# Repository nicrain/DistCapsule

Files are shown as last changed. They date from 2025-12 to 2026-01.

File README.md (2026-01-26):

# Distributeur de Capsules Intelligent (Smart Capsule Dispenser)



**Plateforme:** Raspberry Pi 5 (Bookworm OS) | **État:** Stable (V1.1) | **Dernière mise à jour:** 2026-01-26

Un système de distribution de capsules sécurisé et activé par biométrie. Il transforme un présentoir à capsules standard en un système de "boîte aux lettres" personnalisé où chaque utilisateur a un accès exclusif à un canal de stockage spécifique via une authentification par empreinte digitale. Le système prend en charge l'enregistrement multi-utilisateurs, la hiérarchie des permissions (Admin/Utilisateur) et l'allocation dynamique des canaux physiques.

---

## ✨ Fonctionnalités Clés

*   **Gestion des Rôles Multi-utilisateurs**: Authentification par Token persistante avec connexion automatique (Auto-Login).
*   **Architecture IoT Moderne**: Écosystème complet intégrant l'App Android, le serveur FastAPI et le contrôle matériel en temps réel.
*   **Architecture Multi-threadée**: Threads séparés pour l'IA (visage), l'UI et la gestion des commandes réseau.
*   **UX Mobile Avancée (V1.1)**: Interface visuelle et colorée (Vivid Palette), icône d'application personnalisée, animations de sélection et retour haptique visuel.

---

## 🛠 Architecture Matérielle

*   **Contrôleur**: Raspberry Pi 5 (Recommandé 8Go).
*   **Actionneurs**: 5x Micro servomoteurs SG90 (9g).
*   **Capteur**: Module capteur d'empreintes optique DY-50 / R307 (UART).
*   **Interface**: Écran LCD IPS 1.3" (ST7789) + **Bouton Poussoir (Wake-Up)** pour le réveil du système.
*   **Base**: Composants imprimés en 3D sur mesure. Les premières ébauches sont disponibles dans le répertoire `3D/`.
*   **Alimentation**:
    *   Pi 5: Alimentation officielle USB-C 27W.
    *   Servos: **Alimentation externe 5V** (Masse commune avec le Pi obligatoire).

> **⚠️ Avertissement de Câblage**: Ne pas alimenter 5 servomoteurs directement depuis la broche 5V du GPIO du Pi. Utilisez une source d'alimentation externe. Voir [WIRING_GUIDE.md](docs/WIRING_GUIDE.md) pour les détails de câblage.

---

## 🚀 Installation et Configuration

### 1. Dépendances Système
Le projet dépend de `lgpio` pour le contrôle GPIO sur le Pi 5 et de `pyserial` pour le capteur.

```bash
sudo apt-get update
sudo apt-get install python3-serial python3-pip python3-lgpio python3-pil python3-rpi.gpio
```

### 2. Bibliothèques Python
```bash
sudo pip3 install adafruit-circuitpython-fingerprint st7789
```

### 3. Environnement de Reconnaissance Faciale (Pi 5 Bookworm)
Le système d'exploitation Raspberry Pi OS Bookworm empêche l'installation directe via `pip`. Utilisez l'une des méthodes suivantes :

**Pré-requis (Pi 5) : Pilotes GStreamer**
Pour que la caméra fonctionne avec OpenCV sur le Pi 5, vous devez installer les plugins GStreamer :
```bash
sudo apt install libgstreamer1.0-dev libgstreamer-plugins-base1.0-dev \
gstreamer1.0-plugins-base gstreamer1.0-plugins-good gstreamer1.0-plugins-bad \
gstreamer1.0-libcamera gstreamer1.0-tools
```

**Méthode A : APT (Recommandé)**
```bash
sudo apt update
sudo apt install python3-opencv python3-face-recognition
```

**Méthode B : PIP (Si APT échoue)**
```bash
# L'option --break-system-packages est requise hors d'un environnement virtuel
pip3 install opencv-python face_recognition setuptools --break-system-packages

# ⚠️ Si vous rencontrez l'erreur "Please install `face_recognition_models`" :
pip install git+https://github.com/ageitgey/face_recognition_models --break-system-packages
```

### 4. Configuration Matérielle
*   **UART**: Activez le matériel du port série via `sudo raspi-config`, mais désactivez le shell de connexion. Le module d'empreintes digitales utilise `/dev/ttyAMA0` (GPIO 14/15) sur le Pi 5.
*   **SPI**: Activez l'interface SPI via `sudo raspi-config` pour l'écran.

### 5. Configuration Réseau (Zéro-Config)
Utilisez le script d'installation automatisé pour configurer le Hotspot, l'API et le contrôleur matériel comme services système :

```bash
cd tools
sudo ./install_service.sh
```
*   **SSID** : `DistCapsule_Box` (IP: 192.168.4.1)
*   **Mot de passe** : `capsule_admin`
*   **Port API** : 8000
*   **Démarrage** : Automatique au boot du Pi.

> 🔧 **Administration** : Pour les détails sur l'accès SSH, les logs système et la maintenance SQL, consultez le [**Guide d'Administration (SYSADMIN_GUIDE)**](docs/SYSADMIN_GUIDE.md).

---

## 📱 Application Android (V1.1)

L'application (dossier `android/`) a été optimisée pour une fluidité maximale :

*   **Vivid UI** : Palette de couleurs moderne (Émeraude, Tournesol, Corail) avec texte contrasté pour une lisibilité parfaite.
*   **Auto-Login** : Une fois enregistré, l'accès au Dashboard est instantané.
*   **Connexion Wi-Fi Simplifiée** : Un bouton dédié permet de se connecter automatiquement au hotspot `DistCapsule_Box` sans saisir de mot de passe (Android 10+) ou en ouvrant directement les paramètres (Android 9).
*   **Saisie d'IP Simplifiée** : Entrez simplement l'IP, le protocole et le port sont gérés automatiquement.
*   **Gestion de Compte Sécurisée** : Bouton "Supprimer mon compte" avec nettoyage automatique du token local et des données biométriques sur le matériel.
*   **Feedback Visuel Avancé** : Animation "Pop-up" lors de la sélection des canaux (style réservation de place) et transitions fluides entre les menus.
*   **Navigation Fluide** : Ajout de boutons de retour et gestion intelligente du clavier virtuel pour une expérience sans friction.
*   **Sécurité Administrateur** : Protection contre la suppression accidentelle du compte admin et verrouillage des modifications pour le profil administrateur dans la console de gestion.
*   **Version Production V1.1** : Écosystème IoT complet avec application Android native (Java), serveur FastAPI et agent Python sur Pi 5.
*   **Auto-Guérison (Watchdog)** : Surveillance active du capteur d'empreintes avec réinitialisation automatique en cas de défaillance.
*   **Soutenance & Documentation** : Support de présentation LaTeX complet (21 slides) détaillant l'architecture AAA, les défis techniques et les choix d'ingénierie.
*   **Sécurité \& RGPD** : Authentification par token, protection des comptes administrateurs et fonction "Droit à l'oubli" (nettoyage complet des données biométriques).

---

## 📖 Guide d'Utilisation

### 1. Inscription
Ouvrez l'application, entrez votre nom et cliquez sur "Créer et se connecter". Un canal libre vous sera automatiquement attribué si disponible.

### 2. Administration
Pour activer les privilèges Admin sur un compte :
```bash
sqlite3 capsule_dispenser.db "UPDATE Users SET auth_level=1 WHERE user_id=1;"
```

### 3. Enrôlement Biométrique
Les utilisateurs peuvent lancer l'enrôlement de leur visage ou empreinte directement depuis leur Dashboard. L'écran du Pi s'allume alors automatiquement pour guider l'utilisateur.

---

## 📂 Structure du Projet

| Fichier/Dossier | Description |
| :--- | :--- |
| `main.py` | Cœur du système (Hardware Loop). |
| `api/server.py` | API REST FastAPI. |
| `android/` | Projet Android Studio (Java). |
| `hardware/` | Drivers et logique d'enrôlement. |
| `tools/` | Scripts d'installation et maintenance. |

---

## 🔮 Feuille de Route Future

*   **Notifications Push** : Alertes mobiles en cas d'accès non autorisé.
*   **Logs Avancés** : Historique détaillé des accès avec photos des visages.
*   **Design 3D** : Finalisation de la coque de protection.

---

## 📜 Histoire & Décisions

*   **2026-01-18 (V1.1)** : Refonte de l'UX Android, ajout de l'auto-login et sécurisation des timeouts matériels.
*   **2026-01-14 (V1.0)** : Première release stable IoT (App + API + Pi).
*   **2025-12 (S5)** : Migration vers `lgpio` et architecture asynchrone.

---

*   **Note** : Le projet a abandonné le support MQTT et le suivi des stocks physiques pour se concentrer sur la fiabilité de l'accès biométrique.

## License
MIT License

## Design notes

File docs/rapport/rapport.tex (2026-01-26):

% !TEX program = pdflatex
\documentclass[a4paper,12pt]{report}

\usepackage[T1]{fontenc}
\usepackage[utf8]{inputenc}
\usepackage[french]{babel}
\usepackage{lmodern}
\usepackage{helvet}
\renewcommand{\familydefault}{\sfdefault}

\usepackage{geometry}
\geometry{margin=2.5cm}

\usepackage{graphicx}
\graphicspath{{../slides/pic/}}
\usepackage{float}
\usepackage{booktabs}
\usepackage{longtable}
\usepackage{array}
\usepackage{multirow}
\usepackage{hyperref}
\hypersetup{colorlinks=true, linkcolor=blue, urlcolor=blue, citecolor=blue}

\usepackage{listings}
\usepackage{xcolor}
\lstset{
  basicstyle=\ttfamily\small,
  keywordstyle=\color{blue!70!black}\bfseries,
  commentstyle=\color{gray!70},
  stringstyle=\color{green!40!black},
  breaklines=true,
  frame=single,
  numbers=left,
  numberstyle=\tiny\color{gray},
  showstringspaces=false
}

\usepackage{tikz}
\usetikzlibrary{shapes,arrows,positioning}

\title{DistCapsule : Distributeur connecté biométrique de capsules\\Projet AAA }
\author{Zhaoyu WANG \and Xinqi TANG}
\date{\today}

\begin{document}

% Page de titre sans numéro
\pagenumbering{gobble}
\begin{titlepage}
\centering
\noindent
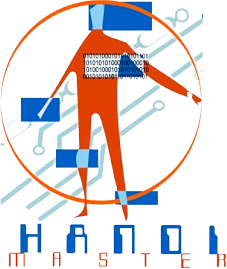
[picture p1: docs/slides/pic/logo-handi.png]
\hfill
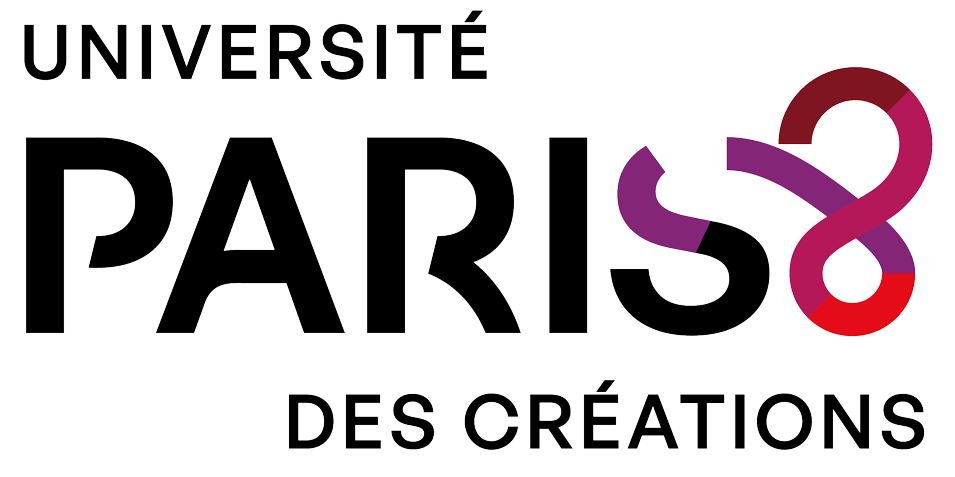
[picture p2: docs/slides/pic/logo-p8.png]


\vspace{0.6cm}

{\large Rapport du Projet AAA\par}

\vspace*{1.6cm}

{\LARGE\bfseries DistCapsule \par}
\vspace{0.4cm}

\vspace{1.4cm}

{\large Zhaoyu WANG \; et \; Xinqi TANG\par}

\vspace{0.8cm}

{\large Professeurs encadrants :\\
Salvatore Anzalone et Dominique Archambault\par}

\vfill

{\large Université Paris 8\\Master Technologies et Handicaps\par}
\vspace{0.4cm}
%{\large \today\par}
\end{titlepage}

% Préliminaires (numérotation romaine)
\cleardoublepage
\pagenumbering{roman}
\pagestyle{plain}

\begin{abstract}
DistCapsule a pour objectif de transformer un présentoir à capsules (5 canaux) en un système embarqué \textbf{sécurisé et personnalisé}.
L’accès aux canaux est contrôlé par biométrie (empreinte et/ou visage) avec gestion multi-utilisateurs et hiérarchie des droits (admin / utilisateur).

L’architecture suit un modèle AAA (3-tiers) : \textbf{Android} pour l’IHM, \textbf{FastAPI} comme passerelle (authentification, orchestration et insertion en base), et \textbf{Raspberry Pi 5} comme exécutant (polling des commandes, contrôle des servos, affichage, biométrie locale).
Ce rapport synthétise les choix techniques, l’implémentation (code), la partie mécanique (fabrication 3D) et les résultats obtenus.
\end{abstract}

\cleardoublepage
\tableofcontents

% Corps du rapport (numérotation arabe)
\cleardoublepage
\pagenumbering{arabic}

\chapter{Contexte et objectifs}
\section{Constat}
Dans un espace café partagé, les capsules sont souvent mélangées ou stockées de manière dispersée, ce qui entraîne :
\begin{itemize}
  \item une occupation inutile de l'espace ;
  \item une organisation difficile (capsules mélangées, accès non contrôlé) ;
  \item une difficulté pour les utilisateurs à identifier leurs propres stocks.
\end{itemize}

\section{Objectifs et contraintes}
En s’appuyant sur le cahier des charges et sur l’implémentation finale, les objectifs sont :
\begin{itemize}
  \item transformer le présentoir en un système à \textbf{5 canaux indépendants} (logique de « boîte aux lettres ») ;
  \item supporter au moins 5 utilisateurs, avec deux rôles : \textbf{administrateur / utilisateur} ;
  \item réaliser la biométrie et le stockage \textbf{en local} (pas de cloud) pour la confidentialité ;
  \item fournir une application Android pour l’inscription, l’affectation des canaux, l’enrôlement et l’ouverture ;
  \item s’adapter aux spécificités du Raspberry Pi 5, notamment la compatibilité GPIO (puce RP1).
\end{itemize}

\chapter{Architecture globale (AAA / 3-tiers)}
\section{Rôles des composants}
Le système est structuré en trois couches :
\begin{itemize}
  \item \textbf{Android (Client)} : interface utilisateur, persistance du token, gestion des comptes et affectation visuelle des canaux.
  \item \textbf{FastAPI (Gateway)} : API REST, authentification via token, accès SQLite, mise en file des commandes (table \texttt{Pending\_Commands}).
  \item \textbf{Core Agent (Executor, Pi 5)} : polling des commandes, action matérielle (servos/écran), biométrie locale, journalisation.
\end{itemize}

\section{Schéma d'architecture}
\begin{figure}[H]
  \centering
  \begin{tikzpicture}[node distance=2.6cm, auto, thick]
    \node[draw, fill=green!20, minimum height=1.2cm, minimum width=3.2cm, align=center] (Android) {\textbf{Android}\\Client};
    \node[draw, fill=blue!20, minimum height=1.2cm, minimum width=3.4cm, align=center, right=3.5cm of Android] (API) {\textbf{FastAPI}\\Gateway};
    \node[draw, fill=red!20, minimum height=1.2cm, minimum width=3.6cm, align=center, right=3.5cm of API] (Pi) {\textbf{Raspberry Pi 5}\\Core Agent};

    \draw[<->] (Android) -- node[above] {REST / JSON} (API);
    \draw[<->] (API) -- node[above] {SQLite\,+ Polling} (Pi);
  \end{tikzpicture}
  \caption{Architecture AAA (3-tiers) de DistCapsule}
\end{figure}

\section{Flux de données (chaîne de traitement)}
Exemple de scénario : l'utilisateur demande l'ouverture d'un canal depuis l'application.
\begin{enumerate}
  \item l'application envoie \texttt{POST /command/unlock?channel=\{1..5\}} ;
  \item FastAPI insère une entrée dans \texttt{Pending\_Commands} (statut \texttt{pending}) ;
  \item le Core Agent récupère la commande la plus ancienne, passe en \texttt{processing} ;
  \item le Core Agent actionne le servo, met à jour l'écran, et journalise dans \texttt{Access\_Logs} ;
  \item la commande est marquée \texttt{completed} ; l'application peut consulter l'état des commandes d'enrôlement via \texttt{/command/poll/\{user\_id\}}.
\end{enumerate}

\begin{figure}[H]
  \centering
  
  \caption{Schéma de flux de données}
\end{figure}

\section{Réseau : topologie et mode de déploiement}
Pour fonctionner sans Internet, le Raspberry Pi 5 opère en mode point d'accès Wi-Fi :
\begin{itemize}
  \item SSID : \texttt{DistCapsule\_Box} (réseau typique \texttt{192.168.4.x}, Pi souvent \texttt{192.168.4.1}) ;
  \item API : port \texttt{8000} ;
  \item administration : liaison Ethernet \texttt{eth0} vers un PC (réseau typique \texttt{192.168.3.x}, Pi souvent \texttt{192.168.3.14}) pour SSH et diagnostic.
\end{itemize}

\begin{figure}[H]
  \centering
  \begin{tikzpicture}[node distance=2.5cm, auto, thick]
    \node[draw, fill=green!20, minimum size=0.9cm, align=center] (Phone) {\textbf{Application}\\Android};
    \node[draw, fill=red!20, minimum width=3.2cm, minimum height=1.2cm, align=center, right=3.0cm of Phone] (Pi) {\textbf{Raspberry Pi 5}\\wlan0 (Point d'accès) + eth0};
    \node[draw, fill=blue!20, minimum size=0.9cm, align=center, right=3.0cm of Pi] (PC) {\textbf{Poste admin}\\SSH/Logs};
    \draw[<->] (Phone) -- node[above] {Wi-Fi} node[below] {192.168.4.x} (Pi);
    \draw[<->] (Pi) -- node[above] {RJ45} node[below] {192.168.3.x} (PC);
  \end{tikzpicture}
  \caption{Topologie réseau (point d'accès Wi-Fi + Ethernet)}
\end{figure}

\chapter{Matériel et câblage}
\section{Périphériques intégrés}
\begin{itemize}
  \item Contrôleur : Raspberry Pi 5 ;
  \item Actionneurs : 5 servomoteurs SG90 ;
  \item Capteurs : empreinte DY-50 (UART), Camera Module 3 (CSI) ;
  \item IHM locale : écran IPS 1.3\," ST7789 (SPI) + bouton de réveil (GPIO 26).
\end{itemize}

\section{Câblage et alimentation}
\subsection{Servos : mapping GPIO (Soft-PWM)}
L'implémentation utilise \texttt{lgpio} en PWM logiciel pour piloter 5 servos (contournement des canaux PWM matériels limités sur Pi 5 et incompatibilité RPi.GPIO) :

\begin{table}[H]
\centering
\begin{tabular}{llll}
\toprule
Canal (servo) & BCM GPIO & Broche (Pin) & Remarque \\
\midrule
1 & 18 & Pin 12 & Compatible Hard PWM , utilisé en Soft PWM \\
2 & 6  & Pin 31 & Soft PWM \\
3 & 12 & Pin 32 & Soft PWM \\
4 & 13 & Pin 33 & Soft PWM \\
5 & 19 & Pin 35 & Soft PWM \\
\bottomrule
\end{tabular}
\caption{Mapping des canaux vers GPIO (implémentation)}
\end{table}

\subsection{Écran (SPI) et empreinte (UART)}
\begin{itemize}
  \item ST7789 : SPI0 (SCLK/MOSI) + DC/RESET/BLK via GPIO ;
  \item Empreinte : \texttt{/dev/ttyAMA0} (GPIO 14/15), TX/RX croisés.
\end{itemize}

\subsection{Alimentation et stabilité}
\begin{itemize}
  \item Les servos sont alimentés par une source 5V externe, avec masse commune avec le Pi ;
  \item Un condensateur (ex. 500\,$\mu$F) est intégré pour amortir les pics de courant.
\end{itemize}

\begin{figure}[H]
  \centering
  
  \caption{Schéma de câblage}
\end{figure}

\chapter{Conception et fabrication 3D}
\section{Fabrication additive}
La modélisation a été réalisée de manière paramétrique avec \textbf{SolidPython2} (interface Python pour OpenSCAD), ce qui a facilité l'ajustement des tolérances et la génération des fichiers STL.

Les pièces ont été imprimées en PLA sur une durée cumulée d'environ 4 jours.
\subsection{Stratégie d'itération}
Pour limiter les itérations longues, l'ajustement dimensionnel a été validé par \textit{prototypage partiel} : au lieu d'imprimer directement les grandes pièces (base, tour), des « échantillons » (ex. encoche du servo, section de rail) ont été imprimés afin de vérifier les contraintes physiques et les tolérances. Cette méthode réduit le coût matière/temps et fiabilise les dimensions avant impression finale.

\begin{figure}[H]
  \centering
  
  \caption{Rendu 3D OpenSCAD du corps principal (structure porteuse)}
\end{figure}

\chapter{Implémentation logicielle}
\section{Core Agent (Pi 5) : boucle principale}
Le cœur du système s'exécute dans \texttt{main.py}. Principes de fonctionnement :
\begin{itemize}
  \item \textbf{SLEEP/ACTIVE} : veille par défaut (rétro-éclairage éteint), réveil par bouton ou commande applicative ;
  \item \textbf{Interrogation périodique (polling)} : lecture des commandes en base (ouverture / enrôlement / suppression) ;
  \item \textbf{Biométrie} : empreinte au premier plan, visage via un fil d'exécution en arrière-plan (file) ;
  \item \textbf{Temporisations} : mise en veille sur inactivité (\texttt{SCREEN\_TIMEOUT}) et durée maximale de session (\texttt{MAX\_SESSION\_TIME}).
\end{itemize}

\section{Passerelle FastAPI (api/server.py)}
FastAPI gère les utilisateurs, l'authentification par token et la mise en file des commandes.
\begin{itemize}
  \item \texttt{POST /users} : création (avec auto-affectation du premier canal libre) ;
  \item \texttt{POST /auth} : auto-login via token lié à l'appareil ;
  \item \texttt{POST /command/unlock}, \texttt{/command/enroll\_...} : insertion dans \texttt{Pending\_Commands}.
\end{itemize}

\section{Application Android : fonctionnalités et intégration}
L'application Android (Java) fournit l'interface utilisateur et s'intègre à l'API via des appels REST/JSON.
Fonctions principales :
\begin{itemize}
  \item \textbf{Authentification} : auto-login par token UUID persisté localement ;
  \item \textbf{Gestion des utilisateurs} : inscription, suppression (selon droits), affectation de canal ;
  \item \textbf{Opérations} : déclenchement d'ouverture de canal et d'enrôlement biométrique via commandes côté API ;
  \item \textbf{Retour d'état} : affichage des canaux et des statuts (disponible/occupé) à partir des données serveur.
\end{itemize}

\begin{figure}[H]
  \centering
  
  \caption{Tableau de bord Android}
\end{figure}

\section{Base de données (SQLite)}
La base est initialisée via \texttt{tools/setup\_database.py}. Tables principales :
\begin{itemize}
  \item \texttt{Users} : identité, droits, canal, token, encodage visage (JSON), statut empreinte ;
  \item \texttt{Access\_Logs} : journal d'événements ;
  \item \texttt{Pending\_Commands} : file de commandes (pending/processing/completed).
\end{itemize}

\section{Biométrie (Visage et Empreinte)}
\begin{itemize}
  \item \textbf{Visage} : \texttt{face\_recognition} (dlib) sur flux vidéo GStreamer/libcamera.
  \item \textbf{Empreinte} : Module DY-50, stockage du modèle dans la mémoire interne du capteur (slot = ID utilisateur).
\end{itemize}

\chapter{Sécurité, confidentialité et approche RGPD}
\section{Confidentialité by design}
\begin{itemize}
  \item Les données biométriques restent \textbf{locales} (pas d'envoi vers un cloud) ;
  \item L'application et l'API n'échangent que le token et les paramètres de commande ;
  \item La suppression d'un compte entraîne la suppression des données associées (base + nettoyage côté capteur).
\end{itemize}

\section{Droits et protection}
\begin{itemize}
  \item L'API interdit la suppression du compte administrateur ;
  \item L'application isole les fonctions d'administration (affectation des canaux) des fonctions utilisateurs.
\end{itemize}

\chapter{Tests et résultats}
\section{Validation bout-en-bout}
Chaînes fonctionnelles validées :
\begin{itemize}
  \item Inscription via l'application $\rightarrow$ token $\rightarrow$ auto-login ;
  \item Enrôlement $\rightarrow$ guidage à l'écran $\rightarrow$ stockage DB/capteur ;
  \item Commande d'ouverture $\rightarrow$ insertion DB $\rightarrow$ exécution mécanique.
\end{itemize}

\section{Limites connues}
\begin{itemize}
  \item Le capteur d'empreintes peut se bloquer (UART) ; une réinitialisation (capteur et/ou service) est parfois nécessaire.
  \item En mode point d'accès, certains téléphones peuvent basculer sur les données mobiles (4G/5G) ; le réglage "Rester connecté" peut être nécessaire.
\end{itemize}

\chapter{Conclusion et perspectives}
DistCapsule est un \textbf{prototype fonctionnel} intégrant application Android, API FastAPI et exécution matérielle sur Raspberry Pi 5.
Il démontre la faisabilité d'un système embarqué connecté sécurisé, respectueux de la vie privée (approche locale) et multi-utilisateurs.

Perspectives :
\begin{itemize}
  \item Améliorer la robustesse du module d'empreintes (gestion d'erreurs UART, stratégie de réinitialisation, éventuellement changement de capteur) ;
  \item Finaliser l'assemblage 3D complet et documenter les tolérances d'impression (PLA) ;
  \item Remplacer le polling par un mécanisme push (ex. WebSockets) pour réduire la latence et la charge ;
  \item Finaliser la logique d'affectation automatique (notamment le canal 1) pour garantir la cohérence UI/API/SQLite lors d'ajouts/suppressions.
\end{itemize}

\appendix
\chapter{Références}
\begin{thebibliography}{9}
  \bibitem{fastapi} FastAPI Documentation. \url{https://fastapi.tiangolo.com/}
  \bibitem{rpi5} Raspberry Pi Documentation. \url{https://www.raspberrypi.com/documentation/}
  \bibitem{android} Android Developers. \url{https://developer.android.com/}
\end{thebibliography}

\end{document}

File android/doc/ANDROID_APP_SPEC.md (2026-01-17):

# 📱 DistCapsule Android App Specification (V2.0)

**Project Name**: DistCapsule (Smart Coffee Capsule Dispenser)
**Target Platform**: Android (Min SDK 24+)
**Backend**: Raspberry Pi 5 (FastAPI REST)
**Version**: 2.0 (Updated 2026-01-16)

---

## 1. Project Overview

The Android application serves as the primary **Control & Management Interface** for the DistCapsule system. It connects to the Raspberry Pi via local Wi-Fi (Hotspot `DistCapsule_Box`) and provides two distinct views based on user roles:
1.  **Administrator**: Full system management (Users, Channels, Hardware).
2.  **Standard User**: Personal coffee retrieval and profile management.

---

## 2. User Roles & Features

### 2.1 Administrator (Admin)
*   **User Management**:
    *   Create new users (Name, Permission).
    *   Assign/Reassign coffee channels (Rails 1-5).
    *   Trigger remote biometric enrollment (Face/Fingerprint).
    *   Delete users (including hardware data cleanup).
    *   *Note*: The App must handle **HTTP 400 errors** if assigning a channel that is already occupied by another user.
*   **Hardware Control**:
    *   Manually open any channel (Maintenance).
    *   View real-time channel occupancy map.

### 2.2 Standard User
*   **One-Tap Dispense**:
    *   Large button "Get My Coffee" (Ouvrir mon canal).
    *   Only works if the user has an assigned channel.
*   **Self-Management**:
    *   Delete own account (GDPR compliance / Unregister).
*   **Visualization**:
    *   View the "Coffee Map" (Which channel is occupied by whom).

---

## 3. App Workflow & UX

### 3.1 Onboarding & Login (Token Based)
*   **No Password**: The app uses a device-bound **Token** for authentication.
*   **First Run (New User)**:
    1.  App scans for the API (`GET /`).
    2.  User clicks "Register".
    3.  App generates a UUID Token.
    4.  **Registration**: App sends Name + Token to server (`POST /users`).
    5.  Server creates user and binds the token immediately.
*   **First Run (Existing User - Lost Phone)**:
    *   *Note*: To prevent identity theft, users cannot self-bind to an existing account.
    *   **Process**: Ask Admin to reset the old binding, or register as a new user.
*   **Subsequent Runs**:
    1.  App sends Token (`POST /auth`).
    2.  Server returns user profile.
    3.  App jumps directly to the Dashboard.

### 3.2 Dashboard (Main Screen)
*   **Header**: "Bonjour, [Name]".
*   **Status Card**: Display icons indicating biometric status (e.g., "Face: ✅ | Finger: ❌") so users know if they are fully enrolled.
*   **Center**:
    *   If **User** + **Assigned Channel**: Big Green Button `[ DISPENSE ]`.
    *   If **Admin**: Grid view of 5 Channels with control buttons.
    *   If **No Channel**: "Waiting for assignment / En attente".
*   **Footer**: "Channel Map" (List of who owns which channel).

### 3.3 Enrollment (Admin Only)
*   Inside User Details:
    *   Button `[ Enroll Face ]` -> Triggers Pi camera mode.
    *   Button `[ Enroll Finger ]` -> Triggers Pi fingerprint sensor mode.
*   **Feedback**: App should show a toast "Enrollment Started, please follow instructions on the machine screen".
*   **Best Practice**: The App should automatically **refresh the user list (`GET /users`)** after a few seconds to update the `has_face` / `has_fingerprint` status icons.

---

## 4. Technical Architecture

### 4.1 Network
*   **Protocol**: HTTP REST (JSON).
*   **Address**: `http://192.168.4.1:8000` (Default Hotspot Gateway).
*   **Constraint**: The phone must stay connected to the Pi's Wi-Fi.

### 4.2 Data Models
*   **User**: `id`, `name`, `auth_level` (1=Admin, 2=User), `assigned_channel` (1-5 or null), `has_face` (bool), `has_fingerprint` (bool).
*   **Command**: The App does not control servos directly. It sends **Commands** (`UNLOCK`, `ENROLL`) to the API, which queues them for the Hardware Agent (`main.py`).

---

## 5. Developer Guide (Next Steps)
For detailed API endpoints, parameters, and JSON examples, please refer to the **[API Reference Documentation](API_REFERENCE.md)**.

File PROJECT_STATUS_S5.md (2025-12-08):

# 智能胶囊分配器 - 项目状态文档 (S5.1)
**日期:** 2025-12-08
**平台:** Raspberry Pi 5 (Bookworm OS)

## 1. 项目概况
本项目旨在构建一个基于 Raspberry Pi 5 的离线智能胶囊分配器。系统通过生物识别（指纹/人脸）验证用户身份，并控制高扭矩舵机分配胶囊。

## 2. 核心架构决策

| 模块 | 决策/规格 | 状态 | 备注 |
| :--- | :--- | :--- | :--- |
| **主控** | Raspberry Pi 5 | ✅ 就绪 | 运行 Raspberry Pi OS (Bookworm) |
| **舵机控制** | **SG90 (9g)** / 软件 PWM | ✅ 更新 | **关键变更**: 从硬件 PWM 迁移到软件 PWM (`lgpio`) 以解决与系统风扇的冲突 |
| **显示屏** | **1.3" IPS (ST7789)** | ✅ 完成 | 240x240, SPI 接口, 自定义驱动 `st7789_driver.py` |
| **数据库** | SQLite (`capsule_dispenser.db`) | ✅ 完成 | 已集成到主程序，支持用户查询和日志记录 |
| **指纹模块** | DY-50 (类 R307) | ✅ 完成 | 解决了 Pi 5 特有的串口映射问题 (`ttyAMA0`) |
| **散热** | 系统风扇 (Active Cooler) | ✅ 恢复 | 由系统内核自动控制，不再占用 GPIO 19 |

---

## 3. 详细技术实现

### 3.1 舵机控制系统 (Servo System)
**重大架构变更 (2025-12-08)**:
由于 Raspberry Pi 5 的硬件 PWM 模块与系统风扇驱动 (`pwm-fan`) 共享时钟源，当风扇启动时，PWM 频率会被强制锁定在 ~25kHz，导致舵机 (需要 50Hz) 失效。
因此，我们将舵机控制迁移到了 **软件 PWM (Software PWM)**，使用 `lgpio` 库直接控制 GPIO 电平。

*   **硬件型号**: SG90 (Micro Servo 9g) x 4
*   **接口分配**:
    *   **Servo 1**: GPIO 18
    *   **Servo 2**: GPIO 12
    *   **Servo 3**: GPIO 13
    *   **Servo 4**: GPIO 19 (已恢复)
*   **系统配置**:
    不再需要复杂的 `config.txt` PWM 覆盖。只需将引脚配置为普通输出模式。
    1.  **配置脚本**: `/usr/local/bin/setup_pwm_pins.sh`
        ```bash
        #!/bin/bash
        # 将 GPIO 12, 13, 18, 19 设置为普通输出模式 (Output)
        pinctrl set 12 op
        pinctrl set 13 op
        pinctrl set 18 op
        pinctrl set 19 op
        ```
*   **核心代码**: `servo_control.py`
    *   使用 `lgpio` 库生成 50Hz PWM 信号。
    *   **防抖逻辑**: 动作完成后立即关闭 PWM 输出 (`duty=0`)，防止舵机抖动并节省电力。

### 3.2 显示系统 (Display)
*   **硬件**: 1.3寸 IPS 屏幕 (ST7789 驱动芯片)。
*   **驱动**: 自研驱动 `st7789_driver.py`。
    *   使用 `spidev` 直接操作 SPI 总线。
    *   解决了第三方库在 Pi 5 上无法初始化的问题。
*   **功能**: 显示系统状态、指纹提示、时间等。
*   **UI 优化**:
    *   安装了 `fonts-dejavu-core` 以支持矢量字体。
    *   字体大小已调整为 **32px (标题)** 和 **22px (正文)**，提升可读性。

### 3.3 数据库设计 (Database)
*   **文件**: `capsule_dispenser.db`
*   **表结构**:
    1.  **Users**: 存储 `user_id`, `name`, `auth_level`, `finger_print_path` 等。
    2.  **Access_Logs**: 记录所有操作日志 (`timestamp`, `event_type`, `status`)。
    3.  **System_Settings**: 键值对配置 (如 `UNLOCK_DURATION=15`)。

### 3.4 指纹模块 (Fingerprint)
*   **硬件**: DY-50 (光学指纹模块, 6线制)。
*   **通信接口**: **UART0** (GPIO 14/15)。
*   **关键配置**:
    *   **端口映射**: 在 Pi 5 上必须使用 **`/dev/ttyAMA0`**。
    *   **系统设置**: 必须禁用 Serial Console。

---

## 4. 当前文件清单

```text
/home/cafe/projet/
├── main_demo.py           # [主程序] 集成指纹、屏幕、舵机 (软件 PWM)
├── servo_control.py       # [驱动] 基于 lgpio 的软件 PWM 舵机控制器
├── st7789_driver.py       # [驱动] 自研 ST7789 屏幕驱动
├── fingerprint_enroll.py  # [工具] 指纹录入脚本
├── setup_database.py      # [配置] 数据库初始化脚本
├── add_user.py            # [工具] 添加测试用户脚本
├── capsule_dispenser.db   # [数据] SQLite 数据库文件
├── WIRING_GUIDE.md        # [文档] 硬件接线指南
└── PROJECT_STATUS_S5.md   # [文档] 本文件
```

## 5. 下一步计划 (Next Steps)

1.  **摄像头集成 (Camera)**:
    *   配置 Pi Camera。
    *   实现人脸识别或二维码扫描，作为第二验证手段。
2.  **Web 管理界面**:
    *   搭建 Flask 服务器。
    *   实现远程查看日志、管理用户和远程开锁。
3.  **硬件封装**:
    *   设计外壳，将所有模块固定。

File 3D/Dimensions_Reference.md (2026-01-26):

# Spécifications Techniques - Support Capsules

## Produit Identifié
*   **Nom :** MOLEDINO Rangement Capsule Mural pour Nespresso Original
*   **Capacité :** 30 Capsules (5 colonnes x 6 capsules)
*   **Matériau :** Acrylique (Transparent & Noir)
*   **Lien Amazon :** [https://www.amazon.fr/dp/B0F2TBTMN4](https://www.amazon.fr/dp/B0F2TBTMN4)

## Dimensions Physiques
*   **Hauteur (H) :** 32 cm
*   **Largeur (L) :** 26 cm
*   **Épaisseur (P) :** 1.2 cm (12 mm)

## Notes de Conception pour la Base
*   Le support est plat et conçu pour être mural.
*   La base doit probablement maintenir ce panneau verticalement ou avec une légère inclinaison.
*   Il faudra prévoir des logements pour les 5 servomoteurs (SG90) en bas de chaque colonne pour le mécanisme de distribution.

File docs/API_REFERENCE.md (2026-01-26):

# 📡 DistCapsule API Reference (V2.0)

**Base URL**: `http://<PI_IP>:8000` (Default: `192.168.4.1:8000`)
**Format**: JSON

---

## 1. Authentication & Session

### 1.1 Login (Auto Auth)
Retrieves current user info using the stored token.
*   **POST** `/auth`
*   **Body**:
    ```json
    { "token": "uuid-string-generated-by-android" }
    ```
*   **Response**: `User Object` (see below) or `401 Unauthorized`.

---

## 2. User Management

### 2.1 Get All Users
Returns a list of all users and their status.
*   **GET** `/users`
*   **Response**: `[User, User, ...]`

### 2.2 Create User (Register & Bind)
Creates a new user and optionally binds the current device token.
*   **POST** `/users`
*   **Body**:
    ```json
    {
      "name": "Jean Dupont",
      "auth_level": 2,        // 1=Admin, 2=User
      "assigned_channel": 1,  // Optional (1-5)
      "app_token": "uuid..."  // Optional: Bind device immediately
    }
    ```
*   **Response**: `User Object` (Newly created)

### 2.3 Update User (Reassign Channel)
*   **PATCH** `/users/{user_id}`
*   **Body** (All fields optional):
    ```json
    {
      "name": "New Name",
      "assigned_channel": 2   // Send null to release channel
    }
    ```
*   **Response**: `User Object` (Updated)
*   **Errors**: Returns `400` if the target channel is already occupied.

### 2.4 Delete User
Removes database record AND clears fingerprint data.
*   **DELETE** `/users/{user_id}`
*   **Response**: `{"status": "success"}`

---

## 3. Remote Commands (Control)

### 3.1 Dispense / Unlock
Opens a specific channel.
*   **POST** `/command/unlock?channel=1`
*   **Response**: `{"status": "success"}`

### 3.2 Trigger Face Enrollment
Puts the machine into face recording mode.
*   **POST** `/command/enroll_face?user_id=12`

### 3.3 Trigger Fingerprint Enrollment
Puts the machine into fingerprint recording mode.
*   **POST** `/command/enroll_finger?user_id=12`

### 3.4 Poll Command Status (Enrollment)
Checks the status of the latest asynchronous command (e.g., enrollment) for a user.
*   **GET** `/command/poll/{user_id}`
*   **Response**:
    ```json
    {
      "cmd_id": 55,
      "command_type": "ENROLL_FINGER",
      "status": "success",     // pending, success, failed, timeout
      "detail_message": "Fingerprint stored at ID 12"
    }
    ```

---

## 4. Data Models

### User Object
```json
{
  "user_id": 12,
  "name": "Jean Dupont",
  "auth_level": 2,
  "assigned_channel": 1,    // null if no channel
  "has_face": 1,            // 1=Yes, 0=No
  "has_fingerprint": 0,     // 1=Yes, 0=No
  "is_active": 1
}
```

### Log Object
```json
{
  "log_id": 101,
  "user_id": 12,
  "timestamp": "2026-01-16 14:30:00",
  "event_type": "APP_UNLOCK",
  "status": "SUCCESS",
  "detail_message": "Channel 1 unlocked via App"
}
```

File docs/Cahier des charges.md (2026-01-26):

## 智能胶囊分配器项目规格说明书 (Cahier des Charges - V1.1 As-Built)

### I. 整体目标与概念 (Objectifs Généraux)

| 编号 | 项目名称 | 描述 |
| :--- | :--- | :--- |
| **P1.0** | **项目名称** | DistCapsule: Distributeur de Capsules Intelligent (智能胶囊分配器) |
| **P1.1** | **核心理念** | 将商用胶囊展示架改造为具有**生物识别身份认证**和**通道访问控制**功能的个人专属存储系统。 |
| **P1.2** | **架构演进** | V1.1 版本已完全摒弃单片机辅助（Arduino/ESP32），采用 **Raspberry Pi 5 全托管架构**，通过 `lgpio` 直接驱动硬件，配合 FastAPI 提供移动端服务。 |
| **P1.3** | **用户支持** | 支持多用户管理，每位用户可绑定 1 个物理通道，并通过 Android App 进行可视化管理。 |

### II. 功能需求 (Exigences Fonctionnelles)

| 编号 | 模块 | 功能描述 | 状态 |
| :--- | :--- | :--- | :--- |
| **F2.1** | **用户管理** | 数据库 (SQLite) 存储用户 ID、Token、权限 (Admin/User) 及生物识别状态。 | ✅ V1.0 |
| **F2.1.1** | **App 注册/登录** | Android App 基于 UUID Token 实现**一键注册**与**自动登录**。 | ✅ V1.1 |
| **F2.1.2** | **通道分配** | 管理员可通过 App 的可视化界面 (Vivid UI) 为用户分配或收回物理通道 (1-5)。 | ✅ V1.1 |
| **F2.2** | **人脸认证** | Pi 5 + Camera Module 3 实时识别人脸，比对特征向量 (Tolerance 0.35)。 | ✅ V1.0 |
| **F2.3** | **指纹认证** | DY-50 光学指纹模块 (UART) 实现秒级解锁，含 Watchdog 自愈机制防止硬件死锁。 | ✅ V1.1 |
| **F2.4** | **通道控制** | 认证成功后，SG90 舵机自动开启对应通道闸门，3秒后自动关闭。 | ✅ V1.0 |
| **F2.5** | **远程指令** | App 可通过 Wi-Fi (HTTP API) 发送远程解锁或触发录入模式指令。 | ✅ V1.0 |
| **F2.6** | **反馈交互** | 1.3" IPS 屏幕实时显示欢迎信息、操作提示及错误代码；App 端同步显示状态。 | ✅ V1.0 |

### III. 技术架构与硬件配置 (Architecture Technique)

| 编号 | 约束 | 描述 |
| :--- | :--- | :--- |
| **T3.1** | **主控平台** | **Raspberry Pi 5 (8GB)**。负责所有业务逻辑、视觉处理、API 服务及 GPIO 控制。 |
| **T3.2** | **IO 控制** | **`lgpio` (Python)**。替代 RPi.GPIO，解决 Pi 5 RP1 芯片的兼容性问题，实现 Soft-PWM 舵机控制。 |
| **T3.3** | **通信协议** | **HTTP (FastAPI)**。替代 MQTT，简化架构，提供 RESTful 接口供 Android 调用。 |
| **T3.4** | **供电策略** | **双路供电**：Pi 5 使用官方 27W USB-C 电源；舵机使用**独立 5V/4A 电源适配器**（共地）。 |
| **T3.5** | **生物识别** | 指纹 (UART /dev/ttyAMA0) + 人脸 (OpenCV/Face_Recognition)。 |

---

## 硬件清单 (Liste Matériel Finalisée)

### 一、核心组件 (Unité Centrale)

| 组件 | 规格 | 用途 |
| :--- | :--- | :--- |
| **Raspberry Pi 5** | 8GB RAM | 核心计算单元 |
| **Micro SD** | 32GB Class 10 | 操作系统 (Bookworm) |
| **Camera Module 3** | Wide Angle | 人脸数据采集与识别 |
| **LCD Screen** | 1.3" ST7789 SPI | 本地状态显示 |
| **Fingerprint Sensor** | DY-50 / R307 (UART) | 指纹采集与比对 |
| **Button** | Momentary Push Button | 系统唤醒 (GPIO 26) |

### 二、执行机构 (Actionneurs)

| 组件 | 规格 | 用途 |
| :--- | :--- | :--- |
| **SG90 Servo** | 180° Micro Servo (x5) | 控制 5 个胶囊通道闸门 |
| **3D Printed Parts** | PLA (Custom Design) | 舵机支架、闸门、传感器外壳 |

### 三、电源 (Alimentation)

| 组件 | 规格 | 备注 |
| :--- | :--- | :--- |
| **Pi Power Supply** | USB-C PD 27W | 树莓派官方电源 |
| **Servo Power** | 5V 4A DC Adapter | **独立供电**，防止电流反噬 |
| **DC Jack** | 5.5x2.1mm Socket | 接入外部 5V 电源 |

### 四、软件栈 (Software Stack)

*   **OS**: Raspberry Pi OS (Bookworm)
*   **Backend**: Python 3.11, FastAPI, SQLite, Pydantic
*   **Hardware**: lgpio, opencv-python, adafruit-circuitpython-fingerprint
*   **Mobile**: Android Native (Java), Retrofit, Material Design 3

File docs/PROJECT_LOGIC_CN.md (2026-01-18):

# DistCapsule 演示逻辑大纲 (V3.0 深度版)

本大纲完全同步 LaTeX 幻灯片 (`main.tex`)，旨在支撑 20-30 分钟的技术答辩。

---

## 一、 背景与痛点 (Contexte)
*   **第 1 页：封面**
    *   关键词：Raspberry Pi 5, IoT Biométrique, V1.1 Finale.
*   **第 2-3 页：现状与方案**
    *   **痛点**：不是简单的“防盗”，而是**空间效率**。咖啡角杂乱、胶囊口味难辨、个人存储占地。
    *   **愿景**：从存储工具升级为“智能服务代理”。

---

## 二、 核心架构 (Architecture)
*   **第 4 页：三层分布式架构**
    *   **Client (Java App)**：负责用户交互，作为系统的“遥控器”。
    *   **Gateway (FastAPI)**：中枢节点，处理安全验证、Token 管理、指令入库。
    *   **Executor (Core Agent)**：底层驱动，24/7 轮询任务，执行硬件动作。
*   **第 5 页：指令流转 (Workflow)**
    *   演示“解锁”全过程：App 发送 -> API 校验 -> SQLite 入库 -> Core 驱动舵机 -> 屏幕反馈。
*   **第 6 页：网络稳定性 (Network Logic)**
    *   **标准热点模式**：解释为何选择启用网关（Gateway Enabled）。
    *   **兼容性**：确保 Android 10+ 不会因为“无网络”而断开连接。

---

## 三、 技术挑战与硬核攻克 (Défis Techniques)
*   **第 7 页：Pi 5 的底层变革**
    *   **挑战**：RP1 芯片导致 `RPi.GPIO` 失效。
    *   **解决**：迁移至 `lgpio` 库，重新封装底层操作。
*   **第 8 页：自研 Soft-PWM**
    *   **技术点**：手写软件脉宽调制逻辑，在树莓派 5 上实现 5 路舵机无抖动控制。
*   **第 9 页：自愈系统 (Watchdog)**
    *   **逻辑**：后台线程每 30 秒“体检”指纹模块。
    *   **自动复位**：检测到超时即自动重启串口（Soft Reset），解决硬件偶尔死锁的顽疾。

---

## 四、 移动端体验与安全性 (Mobile UX)
*   **第 10 页：Vivid Palette 设计语言**
    *   🟢 **绿**：就绪/成功。
    *   🟡 **黄**：连接/待办。
    *   🔴 **红**：警告/删除（避免刺眼，保持视觉舒适）。
*   **第 11-12 页：安全加固**
    *   **Admin 锁**：禁止删除管理员，管理界面动态权限控制。
    *   **隐私清理**：Supprimer mon compte = 数据库 + 指纹/人脸特征 + Token 三位一体同步清理。

---

## 三、 工程、制造与电路 (Ingénierie)
*   **第 13 页：Code-to-CAD 参数化建模**
    *   **工具**：OpenSCAD / SolidPython。
    *   **优势**：极速迭代。修改一个直径参数，整个支架模型自动更新。
*   **第 14-15 页：硬件集成**
    *   **连线图**：展示 GPIO, SPI, UART, CSI 的密集整合。
    *   **供电策略**：5V 电机独立供电，防止电压波动冲击树莓派核心。

---

## 六、 总结与展望 (Bilan)
*   **第 16-17 页：项目完成度**
    *   App Polished, API Stable, Hardware Auto-Healing.
*   **第 18 页：结论**
    *   不仅仅是一个分发器，更是一个完整的、尊重隐私的本地化物联网闭环。
*   **第 19 页：提问与演示**
    *   开启实机演示环节。

---
*演讲贴士：在讲“挑战”部分时尽量深入，在讲“UX”部分时展示截图。*

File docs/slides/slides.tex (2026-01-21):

\documentclass[xcolor=table, aspectratio=169]{beamer}
\usepackage{graphicx}

% --- Core French Language Support ---
\usepackage[T1]{fontenc}
\usepackage[utf8]{inputenc}
\usepackage[french]{babel}
\usepackage{listings}
\usepackage{booktabs} 
\usepackage{tikz} 
\usetikzlibrary{shapes,arrows,positioning}
\usetheme{Darmstadt}
\usecolortheme{dolphin}
\usefonttheme{professionalfonts}

% --- Slide numbers (e.g. 5/20) ---
\setbeamertemplate{navigation symbols}{}
\makeatletter
\setbeamertemplate{footline}{%
    \ifbeamer@noframenumbering
        % hide slide numbers on frames marked as noframenumbering
    \else
        \leavevmode%
        \hbox{%
        \begin{beamercolorbox}[wd=\paperwidth,ht=2.25ex,dp=1ex,right]{footline}%
            \usebeamerfont{footline}\insertframenumber/\inserttotalframenumber\hspace*{2ex}
        \end{beamercolorbox}}%
        \vskip0pt%
    \fi
}
\makeatother

\usepackage{csquotes}

\AtBeginSection[]{
\begin{frame}[noframenumbering]
    \frametitle{Sommaire}
    \tableofcontents[currentsection]
\end{frame}
}

%% --- Metadata ---
\title[DistCapsule]{DistCapsule : Distributeur Connecté}
\subtitle{Système Embarqué Connecté sur Raspberry Pi 5}
\author[Z. Wang \& X. Tang]{Zhaoyu WANG et Xinqi TANG}
\date[\today]{Soutenance Finale -- \today}
\institute[M2 MIASHS]{Université Paris 8 \\ Master Technologies et Handicaps}

%% --- Logo Configuration ---
\titlegraphic{
    \hfill
   
}
\logo{}

%% --- Code Snippet Style ---
\lstset{
    basicstyle=\ttfamily\scriptsize,
    keywordstyle=\color{blue!80!black}\bfseries,
    stringstyle=\color{green!60!black},
    commentstyle=\color{gray}\itshape,
    numbers=left,
    numberstyle=\tiny\color{gray},
    frame=shadowbox,
    rulesepcolor=\color{gray},
    breaklines=true,
    language=Python,
    showstringspaces=false
}

\begin{document}

{
\logo{}
\begin{frame}[noframenumbering]
    \titlepage   
\end{frame}
}

% --- Global Table of Contents ---
\begin{frame}[noframenumbering]{Plan de la présentation}
    \tableofcontents
\end{frame}

% ==============================================================================
% SECTION 1: CONTEXTE (3-4 min)
% ==============================================================================
\section{Contexte et Problématique}

\begin{frame}{Le Constat}
    Dans un espace café partagé, les capsules sont souvent mélangées en vrac ou stockées individuellement, encombrant inutilement le plan de travail.
    
    \begin{columns}
        \begin{column}{0.6\textwidth}
            \begin{alertblock}{Problèmes Identifiés}
                \begin{itemize}
                    \item \textbf{Désordre} : Capsules en vrac, boîtes empilées, perte d'espace sur le plan de travail.
                    \item \textbf{Confusion} : Difficulté à distinguer ses propres capsules (variétés similaires).
                    \item \textbf{Stockage} : Certains utilisateurs cachent leurs capsules pour éviter le vol ou le mélange.
                \end{itemize}
            \end{alertblock}
        \end{column}
        \begin{column}{0.38\textwidth}
            \begin{figure}
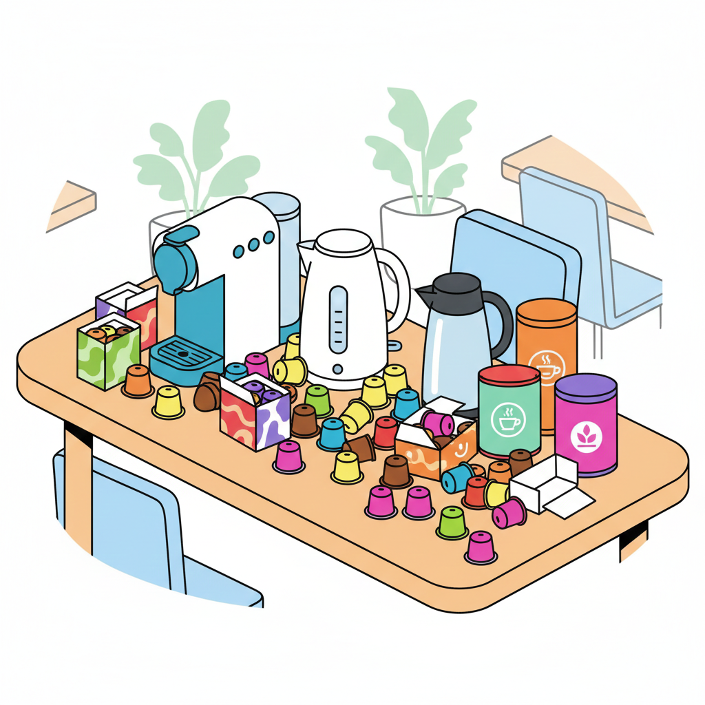
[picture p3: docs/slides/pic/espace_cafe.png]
                
                \caption{Situation actuelle (Stockage passif)}
            \end{figure}
        \end{column}
    \end{columns}
\end{frame}

\begin{frame}{Notre Solution : DistCapsule}
    Transformer un simple présentoir en un \textbf{système embarqué} intelligent.
    
    \vspace{0.3cm}
    \begin{columns}
        \begin{column}{0.6\textwidth}
            \begin{block}{Proposition de Valeur}
                \begin{itemize}
                    \item \textbf{Centralisation} : Une tour compacte stockant 5 variétés.
                    \item \textbf{Personnalisation} : Chaque utilisateur a ses droits d'accès.
                    \item \textbf{Fluidité} : Distribution Biométrique ou via Mobile.
                \end{itemize}
            \end{block}
        \end{column}
        \begin{column}{0.35\textwidth}
            \centering
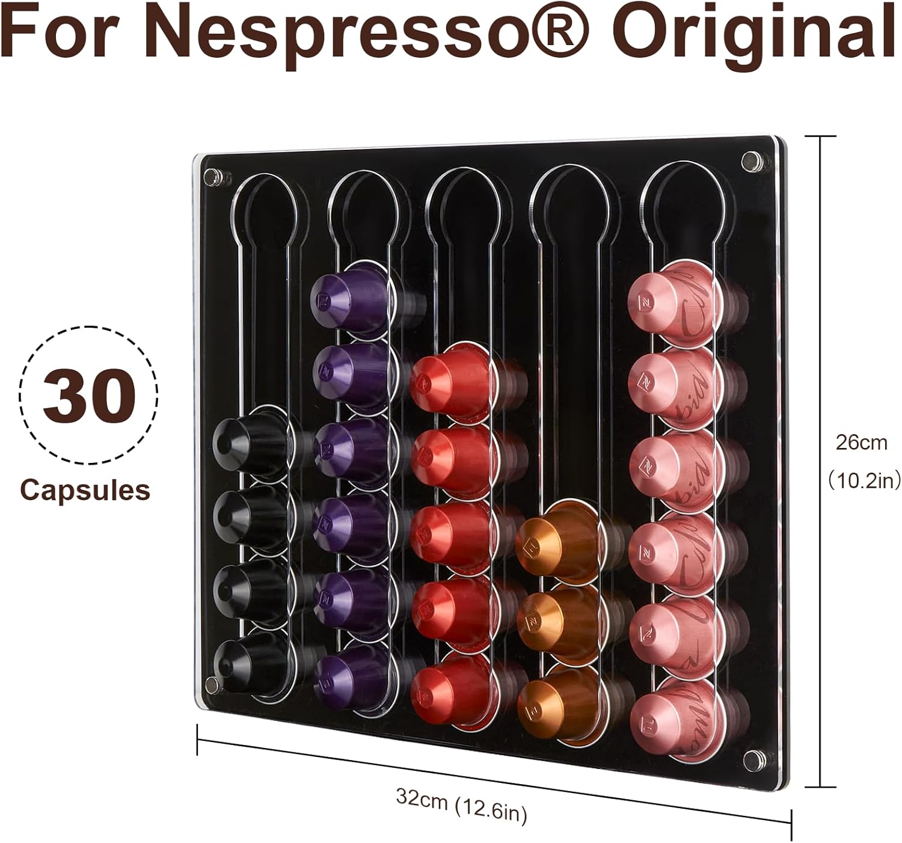
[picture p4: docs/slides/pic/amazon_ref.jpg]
            
            \par\vspace{0.2cm}\small Présentoir à transformer
        \end{column}
    \end{columns}
\end{frame}

% ==============================================================================
% SECTION 2: ARCHITECTURE (5 min)
% ==============================================================================
\section{Architecture Technique}

\begin{frame}{Architecture AAA (3-Tiers)}
    Pour garantir la stabilité, nous avons découplé les responsabilités en trois couches distinctes :
    
    \vspace{0.3cm}
    \begin{center}
    \begin{tikzpicture}[node distance=2.5cm, auto, thick]
        % Nodes - AAA Convention
        \node[draw, fill=green!20, minimum size=1cm, align=center] (Android) {\textbf{Android}\\(Client)};
        \node[draw, fill=blue!20, minimum size=1cm, align=center, right of=Android, node distance=5cm] (Agent) {\textbf{Agent Artificiel}\\(FastAPI)};
        \node[draw, fill=red!20, minimum size=1cm, align=center, right of=Agent, node distance=5cm] (Arduino) {\textbf{Arduino}\\(Raspberry Pi 5)};
        
        % Arrows - Simplified labels
        \draw[<->] (Android) -- node[above] {REST API} (Agent);
        \draw[<->] (Agent) -- node[above] {Commands} (Arduino);
    \end{tikzpicture}
    \end{center}
    
    \begin{itemize}
        \item \textbf{Android} : Interface utilisateur mobile (Java).
        \item \textbf{Agent} : Passerelle de sécurité et orchestration (Python).
        \item \textbf{Arduino} : Contrôle matériel temps réel (lgpio, Servos, Capteurs).
    \end{itemize}
\end{frame}

\begin{frame}{Flux de Données (Workflow)}
    Exemple : Un utilisateur demande une capsule via l'application.
    \vspace{0.2cm}
    \begin{columns}[T]
    \begin{column}{0.35\textwidth}    
    \begin{enumerate}
        \item \textbf{Requête} : \par\texttt{POST} avec Token.
        \item \textbf{Validation} : \par Auth \& Insertion BDD.
        \item \textbf{Exécution} : \par \textbf{Core Agent} (Polling).
        \item \textbf{Action} : \par Pilotage Servo (\texttt{lgpio}).
        \item \textbf{Feedback} : \par Feedback IPS \& App.
    \end{enumerate}
    \end{column}
    \begin{column}{0.65\textwidth}
    \begin{figure}
        \centering
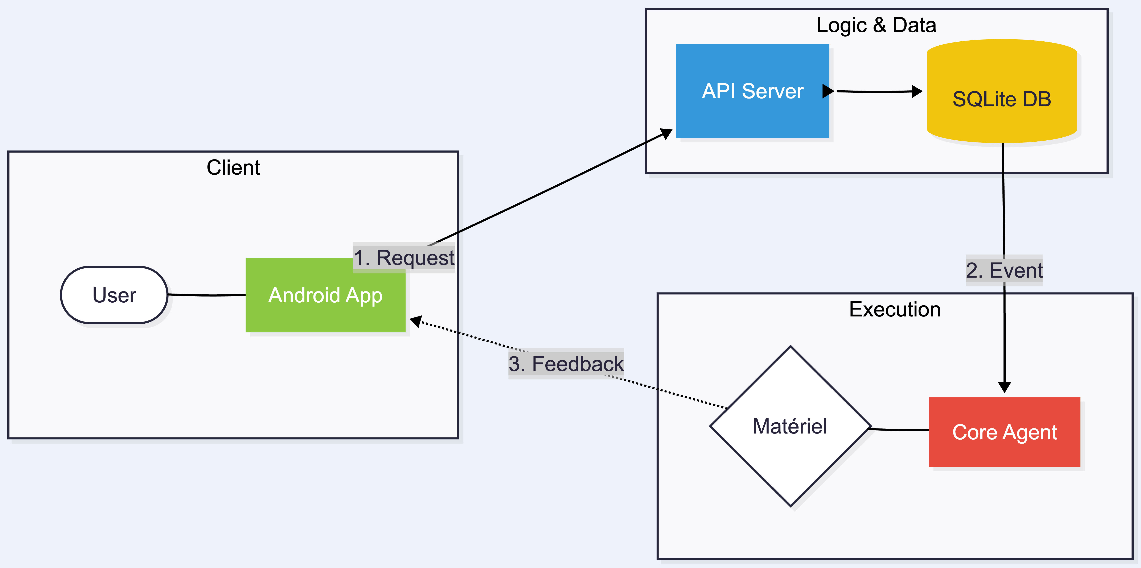
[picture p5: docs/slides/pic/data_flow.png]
        
        \par\vspace{0.2cm}\small Schéma du flux de données entre les composants
    \end{figure}

    \end{column}
    \end{columns}
\end{frame}

\begin{frame}{Réseau : Topologie et Configuration}
    \begin{center}
    \begin{tikzpicture}[node distance=2.5cm, auto, thick]
        % Nodes
        \node[draw, fill=green!20, minimum size=0.8cm, align=center] (Phone) {\textbf{Android}\\App};
        \node[draw, fill=red!20, minimum width=2.5cm, minimum height=1.2cm, align=center, right of=Phone, node distance=5cm] (Pi) {\textbf{Raspberry Pi 5}\\wlan0 (Hotspot) + eth0};
        \node[draw, fill=blue!20, minimum size=0.8cm, align=center, right of=Pi, node distance=5cm] (PC) {\textbf{PC Admin}\\Internet + SSH};
        
        % Arrows
        \draw[<->] (Phone) -- node[above] {\scriptsize Wi-Fi} node[below] {\scriptsize 192.168.4.x} (Pi);
        \draw[<->] (Pi) -- node[above] {\scriptsize RJ45} node[below] {\scriptsize 192.168.3.x} (PC);
    \end{tikzpicture}
    \end{center}
    
    \vspace{0.2cm}
    \begin{columns}
        \begin{column}{0.48\textwidth}
            \textbf{Interface Hotspot (wlan0) :}
            \begin{itemize}
                \item \textbf{SSID} : \texttt{DistCapsule\_Box}
                \item \textbf{IP} : \texttt{192.168.4.1}
                \item \textbf{Port API} : \texttt{8000}
                \item \textbf{Sécurité} : WPA2 + Token
            \end{itemize}
        \end{column}
        \begin{column}{0.48\textwidth}
            \textbf{Interface Ethernet (eth0) :}
            \begin{itemize}
                \item \textbf{IP} : \texttt{192.168.3.14}
                \item \textbf{Usage} : SSH, Internet (Git, Pip install, Mises à jour)
                \item \textbf{Internet} : Accès via PC (ICS)
            \end{itemize}
        \end{column}
    \end{columns}
\end{frame}

% ==============================================================================
% SECTION 3: ARDUINO (Matériel)
% ==============================================================================
\section{Arduino (Raspberry Pi 5 - Matériel)}

\begin{frame}{Raspberry Pi 5 : Composants Intégrés}
    \begin{columns}
        \begin{column}{0.57\textwidth}
            \textbf{Périphériques Connectés :}
            \begin{itemize}
                \item \textbf{5x Servos SG90} : PWM logiciel, GPIO 18/6/12/13/19.
                \item \textbf{DY-50} : Empreintes digitales (UART 57600).
                \item \textbf{Camera Module 3} : Reconnaissance faciale (CSI, IMX708).
                \item \textbf{ST7789 LCD} : Écran 240×240 (SPI).
                \item \textbf{Bouton Wake-Up} : Réveil système (GPIO 26).
            \end{itemize}
            
            \begin{block}{Alimentation}
                Pi 5 : USB-C 27W \par Servos : 5V externe (masse commune)
            \end{block}
        \end{column}
        \begin{column}{0.4\textwidth}
            \centering
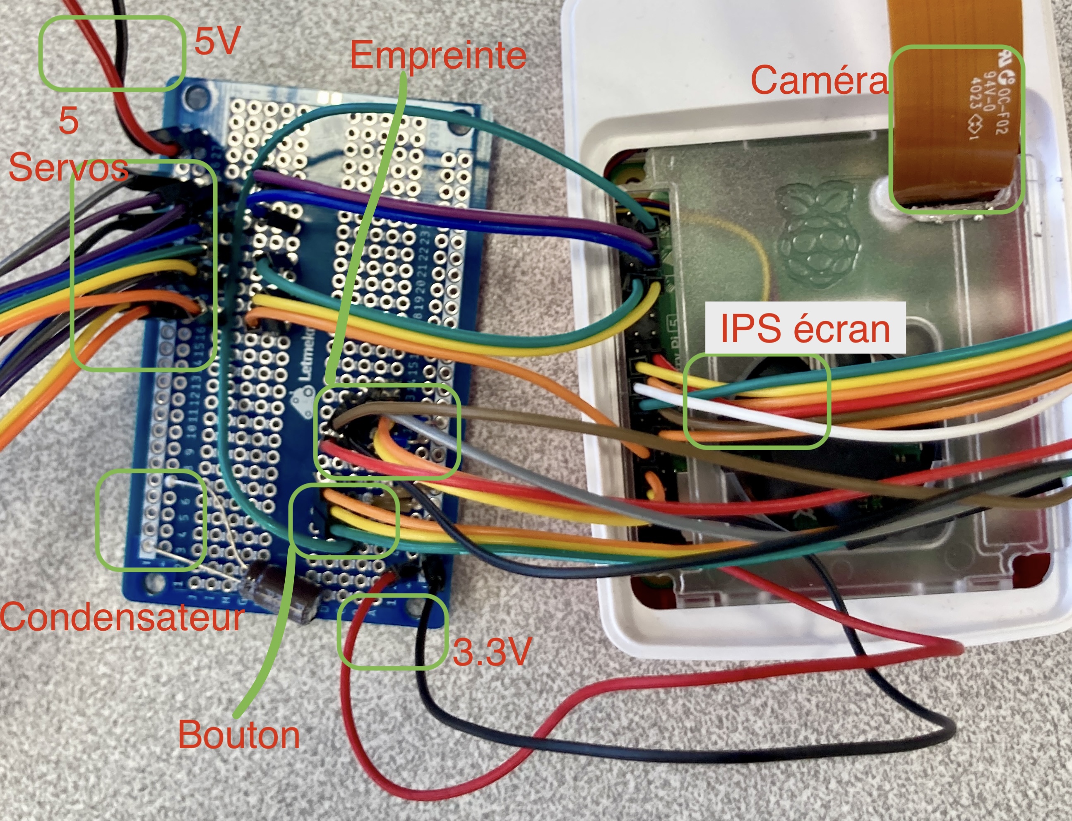
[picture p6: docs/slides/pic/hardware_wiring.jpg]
            
            \par\vspace{0.2cm}\small Câblage réel du prototype
        \end{column}
    \end{columns}
\end{frame}

\begin{frame}{Défi Hardware : La Révolution Pi 5}
    Le passage au Raspberry Pi 5 a cassé la compatibilité de nombreuses bibliothèques historiques.
    
    \begin{itemize}
        \item \textbf{Obsolescence} : \texttt{RPi.GPIO} ne fonctionne pas sur la puce RP1 du Pi 5.
        \item \textbf{Solution} : Migration vers \textbf{\texttt{lgpio}} (Linux GPIO).
    \end{itemize}
    
    \vspace{0.3cm}
    \begin{block}{Innovation : Soft-PWM}
        Pi 5 : 4 canaux HW-PWM (1 réservé ventilateur) $\rightarrow$ Soft-PWM pour 5 servos.
    \end{block}
\end{frame}

\begin{frame}{Câblage et Intégration}
    \begin{center}
    \begin{tikzpicture}[node distance=1cm, auto, thick, scale=0.7, every node/.style={scale=0.7}]
        % Central Pi
        \node[draw, fill=red!20, minimum width=2cm, minimum height=1cm, align=center] (Pi) {\textbf{Pi 5}\\GPIO};
        
        % Direct connections (no breadboard)
        \node[draw, fill=blue!20, minimum width=1.2cm, align=center, above left=0.8cm and 1.2cm of Pi] (LCD) {\textbf{LCD}\\SPI};
        \node[draw, fill=purple!20, minimum width=1.2cm, align=center, above right=0.8cm and 1.2cm of Pi] (Cam) {\textbf{Cam}\\CSI};
        
        % Breadboard (soldered)
        \node[draw, fill=yellow!40, minimum width=3cm, minimum height=0.6cm, align=center, below=1.2cm of Pi] (Bread) {\textbf{Breadboard} (soudé)};
        
        % Through breadboard
        \node[draw, fill=orange!20, minimum width=1.5cm, align=center, below left=0.6cm and 0.3cm of Bread] (Servos) {\textbf{5x SG90}};
        \node[draw, fill=green!20, minimum width=1.2cm, align=center, below=0.6cm of Bread] (Finger) {\textbf{DY-50}};
        \node[draw, fill=gray!20, minimum width=1cm, align=center, below right=0.6cm and 0.3cm of Bread] (Btn) {\textbf{Btn}};
        
        % External 5V
        \node[draw, fill=red!40, minimum width=1cm, align=center, left=2cm of Bread] (Power) {\textbf{5V}};
        
        % Direct connections
        \draw[<->, thick, blue] (Pi) -- node[left] {\tiny direct} (LCD);
        \draw[->, thick, purple] (Cam) -- node[right] {\tiny direct} (Pi);
        
        % Via breadboard
        \draw[<->, thick] (Pi) -- (Bread);
        \draw[->] (Bread) -- (Servos);
        \draw[<->] (Bread) -- (Finger);
        \draw[->] (Bread) -- (Btn);
        \draw[->, red] (Power) -- node[above] {\tiny 5V} (Servos);
        \draw[->, dashed] (Power) |- (Bread);
    \end{tikzpicture}
    \end{center}
    
    \begin{itemize}
        \item \textbf{Connexions directes} : LCD (SPI) + Camera (CSI).
        \item \textbf{Via breadboard} : Servos, Capteur, Bouton + 5V externe + \textbf{condo 500\textmu F}.
    \end{itemize}
\end{frame}

% ==============================================================================
% SECTION 4: AGENT ARTIFICIEL (Backend)
% ==============================================================================
\section{Agent Artificiel (Backend)}

\begin{frame}{Core Agent : Architecture Multi-Threadée}
    Le fichier \texttt{main.py} orchestre toutes les opérations matérielles en temps réel.
    
    \vspace{0.3cm}
    \begin{block}{Modèle Producer-Consumer}
        \begin{itemize}
            \item \textbf{Thread Principal} : Gestion UI, GPIO, polling des commandes API.
            \item \textbf{Thread Face Worker} : Scan facial en arrière-plan (non-bloquant).
            \item \textbf{Thread Watchdog} : Surveillance UART (désactivé).
        \end{itemize}
    \end{block}
    
    \vspace{0.2cm}
    \begin{columns}
        \begin{column}{0.48\textwidth}
            \textbf{Gestion de l'Énergie :}
            \begin{itemize}
                \item 30s inactivité $\rightarrow$ Veille auto.
                \item 5 min max $\rightarrow$ Timeout session.
            \end{itemize}
        \end{column}
        \begin{column}{0.48\textwidth}
            \textbf{API FastAPI :}
            \begin{itemize}
                \item \texttt{/users} : CRUD utilisateurs.
                \item \texttt{/command/*} : Unlock, Enroll.
            \end{itemize}
        \end{column}
    \end{columns}
\end{frame}

\begin{frame}{Approche Testée : Watchdog (Auto-Guérison)}
    \begin{alertblock}{Problème Identifié}
        Le capteur d'empreintes (UART) peut se bloquer de façon aléatoire (cause inconnue).
    \end{alertblock}
    
    \begin{block}{Solution Envisagée}
        Thread de surveillance : vérifie l'état toutes les 30s, tente un soft-reset UART.
    \end{block}
    
    \begin{exampleblock}{Résultat \& Contournement}
        \textbf{Désactivé} : Le soft-reset ne résout pas le blocage. \\
        $\rightarrow$ \textbf{Fallback} : Reconnaissance faciale + App restent fonctionnels. \\
        $\rightarrow$ Seul un \textbf{redémarrage électrique} restaure le capteur.
    \end{exampleblock}
\end{frame}

\begin{frame}{Base de Données : SQLite Schema}
    Architecture de stockage local avec 4 tables principales :
    
    \vspace{0.3cm}
    \begin{table}[]
        \centering
        \footnotesize
        \rowcolors{2}{gray!10}{white}
        \begin{tabular}{l | l | l}
            \toprule
            \textbf{Table} & \textbf{Rôle} & \textcolor{gray}{\textit{Notes}} \\
            \midrule
            \texttt{Users} & Profils utilisateurs & \textcolor{gray}{\scriptsize face\_encoding, has\_fingerprint} \\
            \texttt{Access\_Logs} & Historique d'accès & \textcolor{gray}{\scriptsize timestamp, event\_type} \\
            \texttt{Pending\_Commands} & File commandes API & \textcolor{gray}{\scriptsize status: pending/completed} \\
            \texttt{System\_Settings} & Configuration & \textcolor{gray}{\scriptsize clé-valeur} \\
            \bottomrule
        \end{tabular}
    \end{table}
    
    \vspace{0.3cm}
    \begin{block}{Communication App $\leftrightarrow$ Hardware}
        Via \texttt{Pending\_Commands} : App insère $\rightarrow$ Core Agent poll $\rightarrow$ Exécute.
    \end{block}
\end{frame}

\begin{frame}{Workflow Biométrique}
    \begin{center}
    \begin{tikzpicture}[node distance=0.6cm, auto, thick, scale=0.75, every node/.style={scale=0.75}]
        % Face enrollment flow (left)
        \node[draw, fill=green!20, minimum width=2cm, align=center] (F1) {\textbf{Visage}};
        \node[draw, fill=blue!10, below=of F1, minimum width=2cm, align=center] (F2) {App: POST};
        \node[draw, fill=blue!10, below=of F2, minimum width=2cm, align=center] (F3) {Caméra ON};
        \node[draw, fill=blue!10, below=of F3, minimum width=2cm, align=center] (F4) {Détection};
        \node[draw, fill=blue!10, below=of F4, minimum width=2cm, align=center] (F5) {Encode 128D};
        \node[draw, fill=green!30, below=of F5, minimum width=2cm, align=center] (F6) {SQLite};
        
        \draw[->] (F1) -- (F2);
        \draw[->] (F2) -- (F3);
        \draw[->] (F3) -- (F4);
        \draw[->] (F4) -- (F5);
        \draw[->] (F5) -- (F6);
        
        % Fingerprint enrollment flow (right)
        \node[draw, fill=orange!20, minimum width=2cm, align=center, right=3cm of F1] (P1) {\textbf{Empreinte}};
        \node[draw, fill=blue!10, below=of P1, minimum width=2cm, align=center] (P2) {App: POST};
        \node[draw, fill=blue!10, below=of P2, minimum width=2cm, align=center] (P3) {1ère capture};
        \node[draw, fill=blue!10, below=of P3, minimum width=2cm, align=center] (P4) {Retirer doigt};
        \node[draw, fill=blue!10, below=of P4, minimum width=2cm, align=center] (P5) {2ème capture};
        \node[draw, fill=orange!30, below=of P5, minimum width=2cm, align=center] (P6) {Stocké ID};
        
        \draw[->] (P1) -- (P2);
        \draw[->] (P2) -- (P3);
        \draw[->] (P3) -- (P4);
        \draw[->] (P4) -- (P5);
        \draw[->] (P5) -- (P6);
        
        % Timeout note
        \node[draw, fill=red!20, minimum width=5cm, align=center, below=0.8cm of F6, xshift=2.5cm] (T) {\textbf{Timeout} : 20s (visage) / 30s (empreinte)};
    \end{tikzpicture}
    \end{center}
\end{frame}

% ==============================================================================
% SECTION 5: ANDROID (Client)
% ==============================================================================
\section{Android (Client)}

\begin{frame}{Application Android : Stack Technique}
    \begin{columns}
        \begin{column}{0.55\textwidth}
            \textbf{Technologies :}
            \begin{itemize}
                \item \textbf{Langage} : Java natif (Android Studio).
                \item \textbf{Réseau} : Retrofit2 + OkHttp.
                \item \textbf{Auth} : Token UUID (SharedPreferences).
                \item \textbf{Min SDK} : API 24 (Android 7.0+).
            \end{itemize}
            
            \vspace{0.3cm}
            \textbf{Fonctionnalités Clés :}
            \begin{itemize}
                \item Auto-Login via Token persistant.
                \item Connexion Wi-Fi one-click (Android 10+).
                \item Enrôlement biométrique à distance.
            \end{itemize}
        \end{column}
        \begin{column}{0.4\textwidth}
            \centering
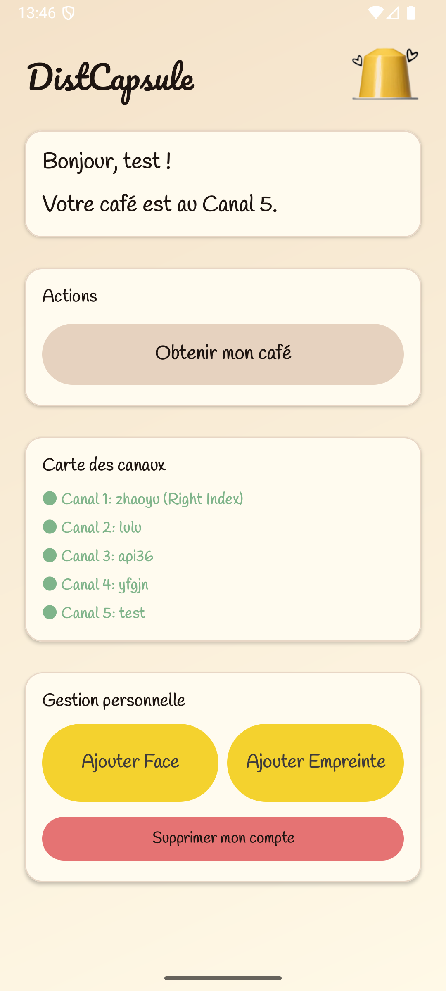
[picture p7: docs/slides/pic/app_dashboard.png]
            
            \par\vspace{0.1cm}\small Dashboard Utilisateur
        \end{column}
    \end{columns}
\end{frame}

\begin{frame}{Design System : "Vivid Palette"}
    L'application (Java) utilise un code couleur sémantique fort pour guider l'utilisateur :
    
    \begin{columns}
        \begin{column}{0.5\textwidth}
            \begin{itemize}
                \item \textcolor[HTML]{2ECC71}{$\blacksquare$ \textbf{Vert (Emerald)}} : Succès, État "Prêt".
                \item \textcolor[HTML]{F1C40F}{$\blacksquare$ \textbf{Jaune (Sunflower)}} : Action requise, Attente.
                \item \textcolor[HTML]{E57373}{$\blacksquare$ \textbf{Rouge (Soft Red)}} : Danger, Suppression.
            \end{itemize}
            \vspace{0.2cm}
            \textbf{Micro-interactions} :
            \begin{itemize}
                \item Animation "Pop-up" lors de la sélection des canaux.
                \item Masquage dynamique des menus admin.
            \end{itemize}
        \end{column}
        \begin{column}{0.45\textwidth}
            \centering
             \hfill
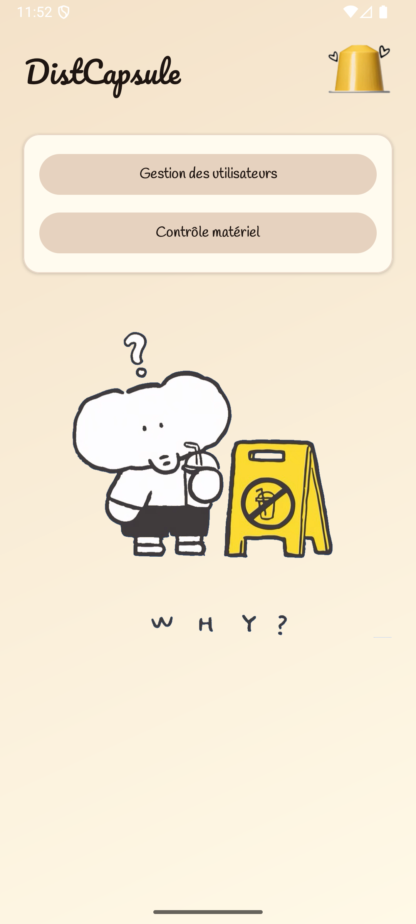
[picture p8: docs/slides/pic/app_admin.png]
            
            \par\vspace{0.2cm}\small Dashboard et Admin Panel
        \end{column}
    \end{columns}
\end{frame}

\begin{frame}{UX : Parcours Utilisateur}
    \begin{columns}
        \begin{column}{0.48\textwidth}
            \textbf{Nouvel Utilisateur :}
            \begin{enumerate}
                \item Lancement App
                \item Token absent $\rightarrow$ Inscription
                \item Nom + Génération Token UUID
                \item Redirection vers Dashboard
            \end{enumerate}
            
            \vspace{0.3cm}
            \textbf{Utilisateur Existant :}
            \begin{enumerate}
                \item Lancement App
                \item Token détecté $\rightarrow$ Auto-Login
                \item Accès direct Dashboard
            \end{enumerate}
        \end{column}
        \begin{column}{0.48\textwidth}
            \textbf{Interface selon Rôle :}
            
            \vspace{0.2cm}
            \textbf{Admin (auth\_level $\leq$ 1) :}
            \begin{itemize}
                \item Gestion des canaux
                \item Création/Suppression users
                \item Enrôlement biométrique
            \end{itemize}
            
            \vspace{0.2cm}
            \textbf{Utilisateur Standard :}
            \begin{itemize}
                \item Déverrouillage One-Tap
                \item Gestion de son profil
            \end{itemize}
        \end{column}
    \end{columns}
\end{frame}

\begin{frame}{Sécurité et Confidentialité}
    \begin{columns}
        \begin{column}{0.48\textwidth}
            \textbf{Protection des Données :}
            \begin{itemize}
                \item \textbf{Stockage local} : Aucun cloud, tout sur Pi.
                \item \textbf{Biométrie} : Encodage 128D (non-réversible).
                \item \textbf{Token UUID} : Auth sans mot de passe.
            \end{itemize}
        \end{column}
        \begin{column}{0.48\textwidth}
            \textbf{Règles Métier :}
            \begin{itemize}
                \item \textbf{Admin protégé} : auth\_level $\leq$ 1 non-supprimable.
                \item \textbf{Droit à l'oubli} : Suppression complète (BDD + capteur).
                \item \textbf{Isolation} : Hotspot local, pas d'internet.
            \end{itemize}
        \end{column}
    \end{columns}
    
    \vspace{0.3cm}
    \begin{block}{RGPD : Conformité par Design}
        Données biométriques jamais transmises $\rightarrow$ Traitement 100\% local.
    \end{block}
\end{frame}

% ==============================================================================
% SECTION 6: INGÉNIERIE (3 min)
% ==============================================================================
\section{Ingénierie et Fabrication}

\begin{frame}{Conception 3D}
    \begin{columns}
        \begin{column}{0.5\textwidth}
            \textbf{Modélisation 3D :}
            \begin{itemize}
                \item Code Python (SolidPython2)
                \item Génère fichiers \texttt{.scad}
                \item Rendu via OpenSCAD
            \end{itemize}
            
            \vspace{0.3cm}
            \textbf{Fabrication :}
            \begin{itemize}
                \item \textbf{Matériau} : PLA
                \item \textbf{Temps} : $\sim$4 jours d'impression
                \item \textbf{Pièces} : 8 modules assemblés
                \item \textbf{Dimensions} : 260 × 260 × 15 mm
            \end{itemize}
        \end{column}
        \begin{column}{0.45\textwidth}
            \centering
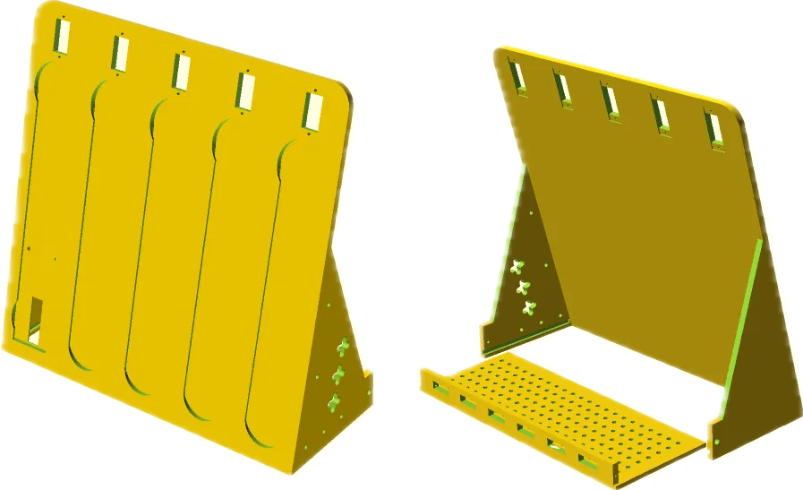
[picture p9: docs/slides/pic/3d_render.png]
             
            \par\vspace{0.2cm}\small Rendu OpenSCAD
        \end{column}
    \end{columns}
\end{frame}

\begin{frame}{Impression 3D : Avancement}
    \begin{columns}
        \begin{column}{0.55\textwidth}
            \textbf{État des Pièces :}
            \begin{table}[]
                \footnotesize
                \rowcolors{2}{gray!10}{white}
                \begin{tabular}{l | l}
                    \toprule
                    \textbf{Pièce} & \textbf{Statut} \\
                    \midrule
                    Base & \textcolor{green!60!black}{\textbf{OK}} \\
                    Tiroir & \textcolor{green!60!black}{\textbf{OK}} \\
                    Bras servo (×5) & \textcolor{orange}{\textbf{2/5}} \\
                    Poussoir (test) & \textcolor{green!60!black}{\textbf{OK}} \\
                    Support périph. & \textcolor{gray}{À concevoir} \\
                    \bottomrule
                \end{tabular}
            \end{table}
        \end{column}
        \begin{column}{0.4\textwidth}
            \textbf{Inspiration :}
            \par Amazon "Capsule Rangement"
            
            \vspace{0.5cm}
            \textbf{Poussoir :}
            \par Pièce expérimentale pour éjecter les capsules automatiquement.
        \end{column}
    \end{columns}
    
    \vspace{0.2cm}
    \begin{block}{Leçon Apprise}
        Imprimer de \textbf{petits prototypes} d'abord pour tester dimensions/assemblage. \\
        \textit{Conseil précieux de Dom — gain de temps et matériau !}
    \end{block}
\end{frame}

% ==============================================================================
% SECTION 7: BILAN (2 min)
% ==============================================================================
\section{Bilan}

\begin{frame}{État Final du Projet}
    \begin{columns}
        \begin{column}{0.5\textwidth}
            \textbf{Stack Technique :}
            \begin{table}[]
                \footnotesize
                \rowcolors{2}{gray!10}{white}
                \begin{tabular}{l | l}
                    \toprule
                    \textbf{Module} & \textbf{Technologie} \\
                    \midrule
                    App Mobile & Android (Java) \\
                    Backend & Python FastAPI \\
                    Hardware & Pi 5 / lgpio \\
                    Mécanique & PLA / SolidPython \\
                    \bottomrule
                \end{tabular}
            \end{table}
        \end{column}
        \begin{column}{0.45\textwidth}
            \textbf{Prochaines Étapes :}
            \begin{itemize}
                \item Finaliser impression 3D
                \item Concevoir support périph.
                \item Enquêter blocage UART
            \end{itemize}
        \end{column}
    \end{columns}
    
    \vspace{0.3cm}
    \begin{block}{Retour d'Expérience}
        Projet complet : Hardware + Software + Mobile + Fabrication.
    \end{block}
\end{frame}

\begin{frame}{Démonstration : Captures d'Écran}
    \begin{columns}
        \begin{column}{0.45\textwidth}
            \centering
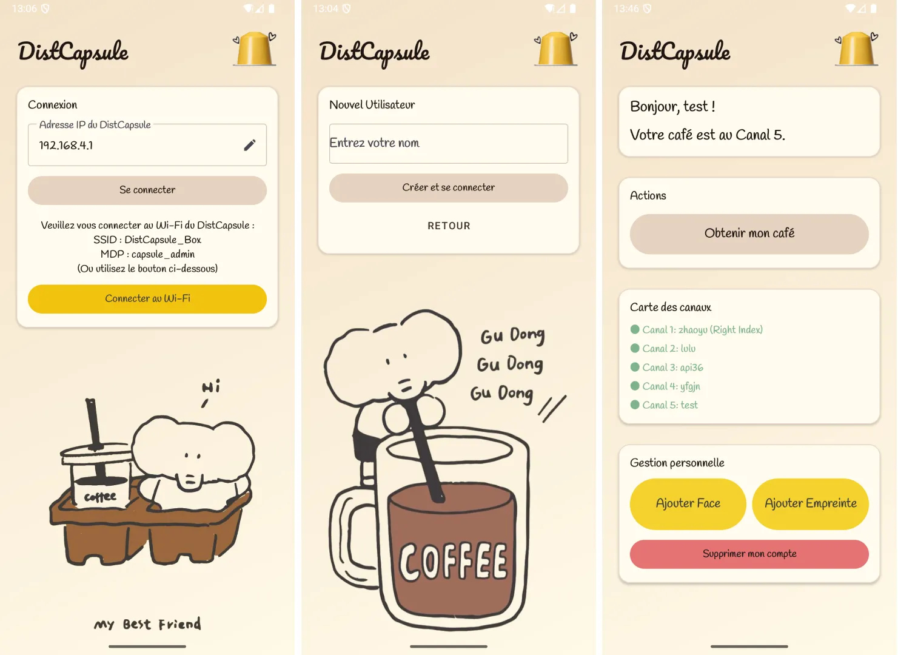
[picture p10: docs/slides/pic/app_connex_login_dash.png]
            
            \par\vspace{0.2cm}\small \textbf{Connexion/Inscription}\\Login automatiquement
        \end{column}
        % \begin{column}{0.32\textwidth}
        %     \centering
        %     \includegraphics[width=0.5\textwidth]{pic/app_dashboard.png}
        %     \par\vspace{0.2cm}\small \textbf{Dashboard}\\Accès utilisateur
        % \end{column}
        \begin{column}{0.45\textwidth}
            \centering
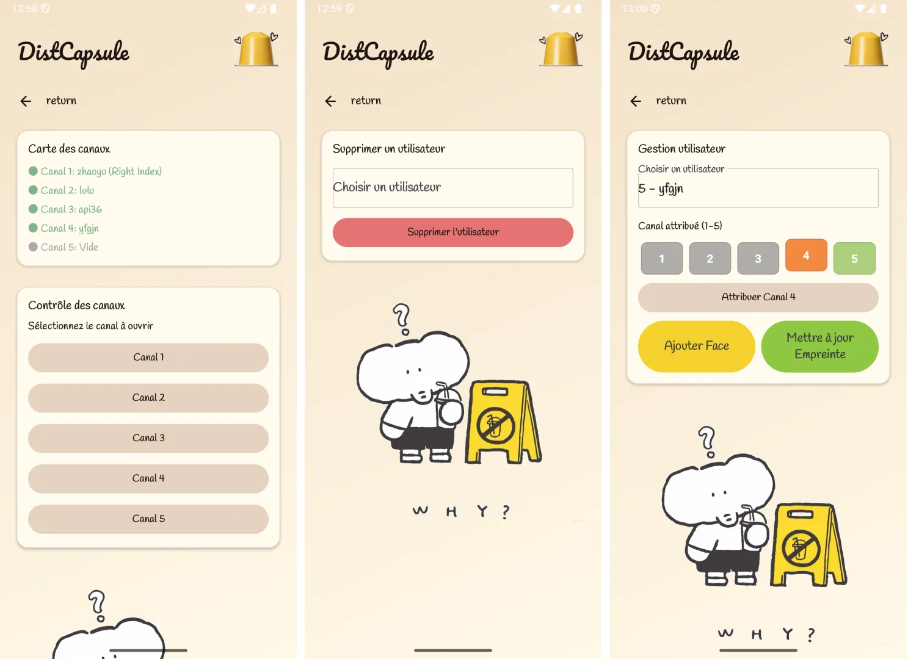
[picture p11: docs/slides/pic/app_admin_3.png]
            
            \par\vspace{0.2cm}\small \textbf{Admin}\\Gestion canaux
        \end{column}
    \end{columns}
    
    \vspace{0.3cm}
    \begin{block}{Interface Vivid Palette}
        \begin{itemize}
            \item \textcolor[HTML]{2ECC71}{$\blacksquare$} Vert = Prêt \quad
            \textcolor[HTML]{F1C40F}{$\blacksquare$} Jaune = Sélection \quad
            \textcolor[HTML]{E57373}{$\blacksquare$} Rouge = Danger
        \end{itemize}
    \end{block}
\end{frame}

\begin{frame}[fragile]{Réflexion : Utilisation de l'IA}
    \begin{columns}
        \begin{column}{0.48\textwidth}
            \textbf{Outils Utilisés :}
            \begin{itemize}
                \item \textbf{Gemini} (principal)
                \item Codex (GPT)
                \item Copilot (Claude Opus)
            \end{itemize}
            
            \vspace{0.2cm}
            \textbf{Avantages :}
            \begin{itemize}
                \item Productivité accrue
                \item Prototypage rapide
            \end{itemize}
        \end{column}
        \begin{column}{0.48\textwidth}
            \textbf{Limites Constatées :}
            \begin{itemize}
                \item Bibliothèques obsolètes
                \item Solutions inutilement complexes
                \item Bugs subtils à relire
            \end{itemize}
            
            \vspace{0.2cm}
            \textbf{Mon Apprentissage :}
            \begin{itemize}
                \item Relecture du code
                \item Compréhension de l'architecture
            \end{itemize}
        \end{column}
    \end{columns}
\end{frame}

\begin{frame}[fragile]{Exemple de Bug IA : Timestamps Incohérents}
    \begin{columns}
        \begin{column}{0.5\textwidth}
            \textbf{Code IA Original :}
            \begin{lstlisting}[language=Python, basicstyle=\scriptsize\ttfamily]
    last_activity_time = time.time()
    session_start_time = time.time()
    last_clock_update = time.time()
    system_state = "ACTIVE"
            \end{lstlisting}
            \vspace{0.2cm}
            \textcolor{red}{$\times$ 3 appels $\rightarrow$ 3 timestamps différents}
        \end{column}
        \begin{column}{0.48\textwidth}
            \textbf{Code Corrigé :}
            \begin{lstlisting}[language=Python, basicstyle=\scriptsize\ttfamily]
    now = time.time()
    last_activity_time = now
    session_start_time = now
    last_clock_update = now
    system_state = "ACTIVE"
            \end{lstlisting}
            \vspace{0.2cm}
            \textcolor{green!60!black}{$\checkmark$ 1 appel $\rightarrow$ timestamps synchronisés}
        \end{column}
    \end{columns}
    
    \vspace{0.3cm}
    \begin{block}{Résultat}
        Avant : Affichage secondes saccadé (0.1s - 2s irrégulier). \\
        Après : Mise à jour fluide et régulière.
    \end{block}
\end{frame}

\begin{frame}{Conclusion}
    DistCapsule a évolué d'un simple concept vers un \textbf{prototype fonctionnel} de distributeur connecté, basé sur un \textbf{système embarqué} (Raspberry Pi 5).
    \vspace{0.5cm}
    
    \textbf{Points forts :}
    \begin{itemize}
        \item Expérience utilisateur fluide (App native, biométrie, parcours simple).
        \item Architecture logicielle découplée (3-tiers, FastAPI, Core Agent multi-thread).
        \item Respect de la vie privée (traitement et stockage 100\% local).
    \end{itemize}
\end{frame}

\begin{frame}{Merci}
    \centering
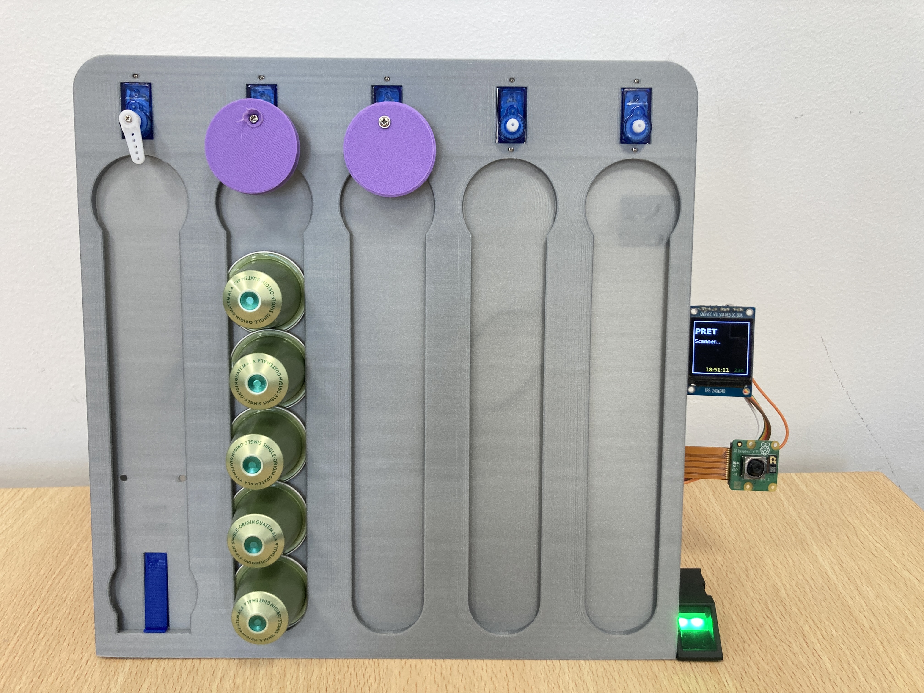
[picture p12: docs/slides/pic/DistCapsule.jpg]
    
    
    \vspace{0.5cm}
    \Large \textbf{Place à la démonstration !}
\end{frame}

\end{document}

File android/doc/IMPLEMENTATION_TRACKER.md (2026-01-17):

# DistCapsule Android App - Implementation Tracker

This document tracks incremental implementation against `doc/ANDROID_APP_SPEC.md`.

## Scope Map (from spec)
- Connection settings (base URL, persistence)
- User list (view ID, permission, channel, active status)
- Logs (who/when/how, recent history)
- Enrollment flow
  - User profile input (name, auth level, assigned channel)
  - Trigger face enrollment
  - Trigger fingerprint enrollment
- Network/Wi-Fi behavior (bind to Wi-Fi if no internet)
- Async feedback (loading/progress for hardware capture)

## Milestones
- Step 1: Data models + users/logs API wiring + basic UI hooks
  - Status: Completed
  - Notes:
    - Added `User` and `LogEntry` models for JSON parsing.
    - `/users` now returns `List<User>`, displayed in spinner and result text.
    - `/logs?limit=50` wired to "Load Log Files" button.
    - Assumes backend JSON fields: `id`, `name`, `auth_level`, `assigned_channel`, `is_active`,
      `timestamp`, `user_id`, `event_type`, `status`.

- Step 2: Enrollment API + request models
  - Status: Completed
  - Notes:
    - Added request/response models for enroll and hardware triggers.
    - Added Retrofit endpoints for `/users/enroll`, `/hardware/enroll_face`,
      `/hardware/enroll_finger`.
    - Assumes response fields include `status` and optional `message`.

- Step 3: Enrollment UI flow
  - Status: Completed
  - Notes:
    - Added form fields for name/auth/channel and enroll button.
    - Added face/fingerprint trigger buttons tied to selected user.
    - Uses spinner selection or last enrolled user ID.

- Step 4: Logs UI improvements
  - Status: Completed
  - Notes:
    - Added log list UI using RecyclerView.
    - Logs render as two-line items (timestamp/user + event/status).

- Step 5: Network binding + async feedback
  - Status: Completed
  - Notes:
    - Added Wi-Fi binding when base URL resolves to local/private host.
    - Added loading indicator and disabled actions during network requests.

- Step 6: Enrollment UX follow-up
  - Status: Completed
  - Notes:
    - After successful enroll, refreshes user list and selects new user in spinner.

- Step 7: Accessibility + UI polish
  - Status: Completed
  - Notes:
    - Switched inputs to Material TextInputLayout for clearer labels.
    - Added headings, live region for status, and touch target minimums.
    - Added labels/content descriptions for spinner, logs, and loading state.

- Step 8: Visual refresh
  - Status: Completed
  - Notes:
    - Introduced cohesive color palette and gradient background.
    - Rebuilt layout with card-based sections and typographic hierarchy.

- Step 9: Coffee palette + spinner UX
  - Status: Completed
  - Notes:
    - Switched UI colors to a coffee-inspired palette.
    - Added spinner dropdown mode and a prompt when user list is empty.

- Step 10: Header icon
  - Status: Completed
  - Notes:
    - Added coffee capsule icon in the header card for visual branding.

- Step 11: Connection UX simplify
  - Status: Completed
  - Notes:
    - Removed Save/Load buttons, replaced with a single editable field.
    - Added pen icon to toggle edit mode and auto-save on done/blur.

- Step 12: Biometric capture layout + French UI
  - Status: Completed
  - Notes:
    - Replaced user dropdown with two side-by-side capture cards.
    - Updated UI strings and runtime messages to French.

- Step 13: Capture cards icons + handwritten title
  - Status: Completed
  - Notes:
    - Added face/fingerprint icons inside capture cards.
    - Applied handwritten font to the main title.

- Step 14: Header free layout
  - Status: Completed
  - Notes:
    - Removed the header card and subtitle line so title + capsule float freely.

- Step 15: Header spacing + capture icon sizing
  - Status: Completed
  - Notes:
    - Added top spacing and horizontal padding for the header row.
    - Expanded face/fingerprint icons to fill the card area.

- Step 16: Enrollment card layout + cafe palette
  - Status: Completed
  - Notes:
    - Moved enrollment card to the left with a cafe image panel on the right.
    - Updated the color palette to match the cafe illustration.

- Step 17: Button palette sync
  - Status: Completed
  - Notes:
    - Tuned "Charger" and "Inscrire" button colors to match cafe palette.

- Step 18: Cafe image fit + Handlee typography
  - Status: Completed
  - Notes:
    - Adjusted cafe image to fit fully within its panel.
    - Applied Handlee font to non-title text (inputs, buttons, section labels).

- Step 19: Cafe2 refresh
  - Status: Completed
  - Notes:
    - Swapped cafe image to cafe2 and updated palette to match.

- Step 20: Cafe2 background removal + contrast
  - Status: Completed
  - Notes:
    - Rendered cafe2 with transparent background and matched card heights.
    - Darkened non-title text for better contrast.

- Step 21: Image fit + bold text
  - Status: Completed
  - Notes:
    - Ensured cafe image stays within the card bounds.
    - Increased non-title text weight for readability.

- Step 22: Cafe2 clean v2 + darker text
  - Status: Completed
  - Notes:
    - Replaced the image with a stronger background-removed version.
    - Darkened non-title text colors for better contrast.

- Step 23: Connection-first flow
  - Status: Completed
  - Notes:
    - Reintroduced a dedicated connection card with base URL input and connect action.
    - Split the UI into steps: connection → enrollment → biometric capture.
    - Hid enrollment/capture/logs/status until the previous step succeeds.

- Step 24: Splash intro + per-step cafe art
  - Status: Completed
  - Notes:
    - Added a splash overlay animation (title pop, capsule drop) before showing the main UI.
    - Added separate connection/enrollment/capture panels with their own cafe cutout images.

- Step 25: V2 auth + role dashboard
  - Status: Completed
  - Notes:
    - Switched to token bind/auth flow and updated API endpoints to V2.
    - Rebuilt UI into Connection → Bind → Dashboard screens.
    - Added biometric status display and actions (unlock, update face/finger, delete user).
    - Added admin-only management panel (select user, enroll, delete) and create-user form.

- Step 26: Channel map + admin channel control
  - Status: Completed
  - Notes:
    - Added channel map for all users and per-user channel status display.
    - Added admin controls to assign channels and manually unlock channels 1-5.

## Open Questions / Assumptions
- Confirm JSON field names and response schemas for `/users` and `/logs`.
- Confirm whether logs should be paged or filtered by user/event type.

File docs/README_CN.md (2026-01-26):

# 智能胶囊分配器 (Smart Capsule Dispenser)



**平台:** Raspberry Pi 5 (Bookworm OS) | **状态:** 稳定 (V1.1) | **最后更新:** 2026-01-26

这是一个安全的、支持生物识别的胶囊分配系统。它将标准的胶囊展示架转变为个性化的“信箱”系统，每个用户通过指纹或人脸认证拥有对特定存储通道的专属访问权。系统支持多用户录入、权限分级（管理员/普通用户）以及物理通道的动态分配。

---

## ✨ 主要功能

*   **全自动 IoT 生态**: 集成原生 Android App、FastAPI 后端以及树莓派硬件控制，实现端到端的无缝连接。
*   **多线程架构**: 独立的人脸识别、UI 刷新和网络指令处理线程，确保在高负载下依然响应迅速。
*   **智能电源管理**: 30秒无操作自动休眠，物理按钮支持即时唤醒。
*   **极致 UX 体验 (V1.1)**: 全新 Vivid 配色方案，支持自动登录、一键注册、自定义 App 图标以及可视化的通道分配界面。

---

## 🛠 硬件架构

*   **控制器**: Raspberry Pi 5。
*   **执行器**: 5x SG90 微型舵机 (9g)。
*   **传感器**: DY-50 光学指纹模块 (UART) + Camera Module 3。
*   **人机交互**: 1.3" IPS LCD + **智能唤醒按钮**。

---

## 🚀 安装与设置

### 5. 网络与 API 配置 (全自动)
使用一键安装脚本，自动配置 Wi-Fi 热点、API 服务器以及硬件主程序作为系统服务运行：

```bash
cd tools
sudo ./install_service.sh
```
*   **Wi-Fi SSID**: `DistCapsule_Box` (192.168.4.1)
*   **Wi-Fi 密码**: `capsule_admin`
*   **API 端口**: 8000
*   **自启**: 树莓派开机后所有服务将自动启动。

> 🔧 **高级管理**: 关于 SSH 连接、服务日志查看及数据库维护指令，请参阅 [**系统管理与运维指南 (SYSADMIN_GUIDE)**](./SYSADMIN_GUIDE.md)。

---

## 📱 Android 移动应用 (V1.1)

配套 App（位于 `android/` 目录）已针对 Pi 5 深度优化：

*   **Vivid UI**: 采用现代色彩体系（绿宝石、向日葵、珊瑚红），确保高对比度与专业感。
*   **自动登录**: 注册后下次打开 App 即刻直达控制台。
*   **简化 IP 输入**: 只需输入 IP，App 自动补全协议与端口。
*   **可视化选座**: 按钮式通道分配，支持动画反馈与冲突检测。
*   **实时同步**: 录入指纹或人脸时，手机端与机器屏幕同步状态。

---

## 📖 使用指南

### 1. 快速注册
打开 App，输入姓名点击“创建并连接”。系统会自动分配第一个空闲通道。

### 2. 提升管理员权限
```bash
sqlite3 capsule_dispenser.db "UPDATE Users SET auth_level=1 WHERE user_id=1;"
```

### 3. 生物识别录入
在 App 中点击“添加面部”或“添加指纹”，树莓派屏幕会自动点亮并引导您完成录入。

---

## 📂 项目结构

| 文件/目录 | 描述 |
| :--- | :--- |
| `main.py` | 硬件主逻辑。 |
| `api/server.py` | FastAPI 后端服务。 |
| `android/` | Android Studio 源代码。 |
| `hardware/` | 硬件驱动与录入逻辑。 |
| `tools/` | 安装与维护工具脚本。 |

---

## 🔮 未来计划

*   **远程推送**: 指令执行成功后的手机通知提醒。
*   **3D 外壳**: 正在完善针对 Pi 5 的全包裹式保护壳设计。

---

## 📜 历史与决策

*   **2026-01 (V1.1)**: **体验革命**。重构 Android UI，增加自动登录，修复硬件死锁漏洞。
*   **2026-01 (V1.0)**: **IoT 闭环**。首次打通 App -> API -> 数据库 -> 硬件链路。
*   **2025-12 (S5)**: **内核重构**。迁移至 `lgpio` 并实现全异步架构。

---

*   **注**: 项目已移除 MQTT 支持与库存追踪功能，以确保生物识别访问的核心稳定性。

## License
MIT License

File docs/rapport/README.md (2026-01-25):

# DistCapsule Rapport (LaTeX)

Ce dossier contient le rapport technique en LaTeX (version fran\c{c}aise, compatible pdflatex).

## Compilation (pdflatex)

```bash
cd docs/rapport
pdflatex main.tex
pdflatex main.tex
```

Avec `latexmk` :

```bash
latexmk -pdf -interaction=nonstopmode -file-line-error main.tex
```

## Images

Le rapport r\'eutilise les images du support de slides via :

```tex
\graphicspath{{../slides/pic/}}
```

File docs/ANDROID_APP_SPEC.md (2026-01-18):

# 📱 DistCapsule Android App Specification (V2.0)

**Project Name**: DistCapsule (Smart Coffee Capsule Dispenser)
**Target Platform**: Android (Min SDK 24+)
**Backend**: Raspberry Pi 5 (FastAPI REST)
**Version**: 1.1 (Updated 2026-01-18)

---

## 1. Project Overview

L'application Android sert d'interface de contrôle principale. Elle a été optimisée en version 1.1 avec une **Vivid UI** (palette de couleurs vive et contrastée) pour une meilleure lisibilité et une réactivité accrue.

---

## 2. User Roles & Features

### 2.1 Administrator (Admin)
*   **User Management**:
    *   Assign/Reassign coffee channels (Rails 1-5) via a **Visual Interface** (buttons with pop-up animations).
    *   Trigger remote biometric enrollment (Face/Fingerprint).
    *   Delete users (instant database update + hardware cleanup).
*   **Hardware Control**:
    *   Manually open any channel.
    *   View real-time channel occupancy map.

### 2.2 Standard User
*   **One-Tap Dispense**:
    *   Large button "Obtenir mon café" (Emerald Green).
*   **Self-Management**:
    *   Delete own account.
    *   **Self-Enrollment**: Launch face/fingerprint enrollment directly from the phone.

---

## 3. App Workflow & UX

### 3.1 Onboarding & Login (Token Based)
*   **Auto-Login**: L'application utilise un Token lié à l'appareil. Une fois enregistré, l'utilisateur accède directement au Dashboard.
*   **First Run (New User)**:
    1.  **One-Click Registration**: Entrez votre nom, cliquez sur "Créer et se connecter".
    2.  Le système attribue automatiquement le premier canal libre.
    3.  L'application génère et stocke le Token UUID.

### 3.2 Dashboard (Main Screen)
*   **Vivid Visuals**:
    *   **Emerald (#2ECC71)**: Actions réussies / Prêt.
    *   **Sunflower (#F1C40F)**: En attente / Sélectionné.
    *   **Coral (#FF5A5F)**: Occupé / Suppression.
*   **Header**: "Bonjour, [Name] ! Votre café est au Canal [X]." (ou message de bienvenue si pas de canal).

---

## 4. Technical Architecture

### 4.1 Network
*   **Smart IP Handling**: L'utilisateur entre simplement l'IP (ex: `192.168.4.1`). L'App gère automatiquement le protocole `http://` et le port `:8000`.
*   **Offline Hotspot**: Connection directe au Pi via `DistCapsule_Box`.

---

## 5. Developer Guide (Next Steps)
La version 1.1 a supprimé le "Mode Demo" pour garantir l'intégrité des sessions réelles. Tout test doit désormais s'appuyer sur une instance API active.

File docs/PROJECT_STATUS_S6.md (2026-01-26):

# Status du Projet DistCapsule (S6) - 2026-01-02
# DistCapsule 项目状态报告 (S6)

## 🔵 État Actuel : Terminé / Completed (S6 - IoT & Mobile)
**Focus**: Transition d'un système autonome (Standalone) vers un écosystème connecté (IoT).
**核心目标**: 从单机智能系统向物联网互联生态转型。

## 🎯 Objectifs de la Phase S6 / 本阶段目标

### 1. Infrastructure Réseau (Pi-Side) / 网络基础设施 (树莓派端)
- [x] **API Web (Flask/FastAPI)**:
    - Créer une API légère pour exposer les logs (`/api/logs`) et l'état du système (`/api/status`).
    - **Web API**: 开发轻量级 API 接口，用于手机端获取日志和系统状态 (GET endpoints OK, POST pending).

### 2. Application Mobile (Android) / 移动端应用
- [x] **App Architecture**: 
    - Tech: Android (Kotlin/Java) ou Cross-platform (Flutter).
    - **App 架构**: 确定技术栈（原生 Android Java）。
- [x] **Fonctionnalités Clés**:
    - **Dashboard**: Visualisation des niveaux de stock et des derniers accès.
    - **App Control**: Bouton "Ouvrir" via App (Wi-Fi Local).
    - **Notifications**: Alerte sur le téléphone quand un utilisateur déverrouille une boîte.
    - **核心功能**: 仪表盘、App 无线开锁(Wi-Fi)、实时通知。

### 3. Sécurité & Stabilité / 安全与稳定
- [x] **Network Recovery**: Gestion automatique de la reconnexion Wi-Fi en cas de coupure.
- [x] **安全加固**: 网络断连后的自动重连机制。

---

## 📅 Journal des Modifications (Changelog)
*   **2026-01-18 (Final S6 Release - V1.1)**:
    *   **Android App v1.1**: Refonte totale de l'UX (Vivid Palette), icône personnalisée, auto-login via Token.
    *   **Wi-Fi Automation**: Bouton de connexion automatique au hotspot `DistCapsule_Box` avec gestion des permissions.
    *   **Logic Cleanup**: Suppression du Mode Demo et de la création d'utilisateur côté Admin au profit du self-service. Nettoyage massif des ressources (strings.xml) pour une stabilité de build accrue.
    *   **Sécurité**: Suppression automatique du token d'accès lors de la suppression du compte. Protection contre la suppression accidentelle de l'administrateur.
    *   **Micro-interactions**: Ajout d'un effet "Pop-up" (TranslationY + OvershootInterpolator) sur les boutons de sélection de canal pour un feedback tactile visuel.
    *   **Fiabilité Matérielle**: Implémentation d'un thread "Watchdog" pour le capteur d'empreintes (DY-50). Il détecte les timeouts UART et effectue un "Soft Reset" automatique.
    *   **Documentation Finale**: Production d'un support de présentation de 20 minutes (LaTeX V3.0) incluant schémas d'architecture, défis techniques (lgpio sur Pi 5) et démonstration de l'UX mobile.
    *   **Qualité de Code**: Nettoyage intégral des ressources Android (strings.xml), suppression des doublons et passage au full UTF-8 pour la documentation. 
        - Blocage total de la suppression des comptes administrateurs (côté API et App).
        - Interface de gestion dynamique : les boutons d'action sont masqués tant qu'un utilisateur n'est pas sélectionné.
        - Verrouillage automatique de l'UI si le profil sélectionné est l'administrateur.
    *   **UX Revolution**: Boutons de retour, gestion intelligente du clavier, et messages Toast conviviaux. Distinction sémantique entre "Supprimer l'utilisateur" (Admin) et "Supprimer mon compte" (Utilisateur).
*   **2026-01-14 (V1.0 Initial IoT Release)**:
    *   Intégration du code source de l'application dans le répertoire `android/`.
    *   Nettoyage des logs (Suppression des Emojis, style professionnel).
    *   Implémentation de la gestion complète des utilisateurs (`POST /users` pour créer, `DELETE /users` pour supprimer avec nettoyage matériel).
*   **2026-01-16**: 
    *   **Docs**: Création des diapositives de présentation (`docs/slides/`) avec architecture AAA et histoire du design 3D.
    *   **Fix Caméra**: Correction de la rotation de 90° (Counter-Clockwise) dans `face_system.py` et `face_enroll.py`.
    *   **IA**: Ajustement du seuil de reconnaissance faciale à 0.35 pour une sécurité accrue.
    *   **UX**: Interface bilingue (Chinois / Français) pour tous les logs, menus et affichages LCD.
    *   **UX**: Clarification des logs (Remplacement du terme "Distance" par "Différence de caractéristiques").
    *   **Wiring**: Mise à jour des broches pour les Servos 2-5 (GPIO 6, 12, 13, 19).
    *   **Architecture**: Simplification (Suppression de MQTT). Focus sur l'API HTTP.
    *   **API**: Correction de la sérialisation Pydantic/SQLite. Endpoints `/users` et `/logs` fonctionnels.
    *   **IoT**: Implémentation du contrôle App via table `Pending_Commands` (Renommé de Remote -> App).
    *   **Hotspot**: Ajout de la passerelle DHCP (192.168.4.1) pour résoudre les problèmes de connexion Android/iOS.
    *   **API**: Ajout des statuts biométriques (`has_face`, `has_fingerprint`) dans la réponse `/users`.
*   **2026-01-02**: Initialisation de la Phase S6. Archivage de la version S5 (Standalone Stable).
    *   **Auth**: Simplification du flux (Suppression de `/bind`, intégration du Token dans `/users` pour l'enregistrement direct).
*   **2026-01-02**: Initialisation de la Phase S6. Archivage de la version S5 (Standalone Stable).

---

## 📝 Notes Techniques
*   L'architecture S5 (Threading/Queue/Event) servira de base solide.
*   S5 的多线程架构将作为坚实基础。

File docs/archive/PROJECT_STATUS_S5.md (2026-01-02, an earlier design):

# Status du Projet DistCapsule (S5) - 2026-01-02
# DistCapsule 项目状态报告 (S5)

## 🟢 État Actuel : Stable (S5) / 当前状态：稳定
Le système est fonctionnel avec une architecture matérielle complète et un logiciel optimisé pour le Raspberry Pi 5.
系统功能正常，拥有完整的硬件架构，且软件已针对 Raspberry Pi 5 进行了优化。

## 🛠 Modifications Récentes (S5) / 近期修改
1.  **Données & Persistance (数据与持久化)** :
    *   **Migration Automatique** : Le script `setup_database.py` détecte et met à jour automatiquement les anciennes structures de base de données (ajout de `face_encoding`).
    *   **自动迁移**：`setup_database.py` 脚本能自动检测并升级旧的数据库结构（如自动添加 `face_encoding` 字段），无需手动重建。

2.  **Architecture Logicielle (软件架构)** :
    *   Passage au **Multi-threading** : `main.py` sépare la reconnaissance faciale (thread arrière-plan) de l'UI (thread principal) pour éviter les blocages.
    *   **多线程重构**：`main.py` 将人脸识别（后台线程）与 UI 界面（主线程）分离，彻底消除了卡顿。
    *   **Migration lgpio** : Abandon total de `RPi.GPIO` au profit de `lgpio` pour éviter les conflits matériels sur le Pi 5.
    *   **迁移至 lgpio**：为了解决 Pi 5 上的硬件冲突，全面弃用 `RPi.GPIO`，转而使用更底层的 `lgpio` 库。

2.  **Expérience Utilisateur (UI/UX) (用户体验)** :
    *   **Compte à rebours linéaire** : Affichage fluide des secondes restantes.
    *   **线性倒计时**：流畅显示剩余秒数。
    *   **Session Interactive** : Bouton physique (GPIO 26) pour le réveil et l'extension du temps ("Keep Alive").
    *   **交互式会话**：通过物理按钮 (GPIO 26) 实现系统唤醒和会话时间延长（“保活”）。
    *   **Réactivité Instantanée** : Utilisation d'interruptions matérielles pour le bouton, éliminant toute latence.
    *   **即时响应**：按钮检测采用边缘检测机制，消除了延迟。
    *   **Sécurité Session** : Timeout automatique après 30s d'inactivité, forçage de l'arrêt après 5 min.
    *   **会话安全**：30秒无操作自动休眠，5分钟强制结束会话。

3.  **Réseau (网络)** :
    *   Scripts de **Hotspot "Silencieux"** : Permet au téléphone de contrôler le Pi (MQTT/HTTP futur) tout en gardant la 4G (`tools/setup_manual_hotspot.sh`).
    *   **静默热点脚本**：允许手机连接树莓派（用于未来的 MQTT/HTTP 控制）的同时，保持手机自身的 4G 上网功能。

## 📋 Liste de Contrôle des Fonctionnalités / 功能核对表
- [x] Contrôle Servo (lgpio) / 舵机控制
- [x] Écran LCD (ST7789) + Horloge / LCD 屏幕 + 时钟
- [x] Capteur Empreinte (DY-50) / 指纹传感器
- [x] Reconnaissance Faciale (OpenCV/GStreamer) / 人脸识别
- [x] Base de données SQLite (Utilisateurs/Logs) / SQLite 数据库
- [x] Bouton de Réveil/Extension / 唤醒与续命按钮
- [x] Installation Service systemd (`capsule.service`) / 系统服务安装
- [x] Documentation complète (FR/CN/Wiring) / 完整文档 (中/法/接线图)

## 🔮 Prochaines Étapes (To-Do) / 下一步计划
1.  **Interface Web (Dashboard)** :
    *   Créer une app Flask/Django locale pour visualiser les logs et gérer les utilisateurs depuis le téléphone.
    *   **Web 仪表盘**：开发一个本地 Flask/Django 应用，以便在手机上查看日志和管理用户。
2.  **Protocole MQTT** :
    *   Implémenter le client MQTT dans `main.py` pour recevoir les commandes d'ouverture à distance.
    *   **MQTT 协议**：在 `main.py` 中实现 MQTT 客户端，以接收远程开锁指令。
3.  **Gestion de Stock** :
    *   Ajouter un compteur de capsules par canal dans la base de données.
    *   **库存管理**：在数据库中增加每个通道的胶囊计数功能。

## 📝 Notes pour la Reprise / 复工备注
*   Pour lancer le système manuellement : `sudo systemctl stop capsule` puis `sudo python3 main.py`.
*   手动启动系统：先停止服务 `sudo systemctl stop capsule`，再运行 `sudo python3 main.py`。
*   Pour mettre à jour le service : `git pull` puis `sudo systemctl restart capsule`.
*   更新服务代码：执行 `git pull` 后运行 `sudo systemctl restart capsule`。
*   Le script de hotspot est `tools/setup_manual_hotspot.sh`.
*   热点配置脚本位于 `tools/setup_manual_hotspot.sh`。

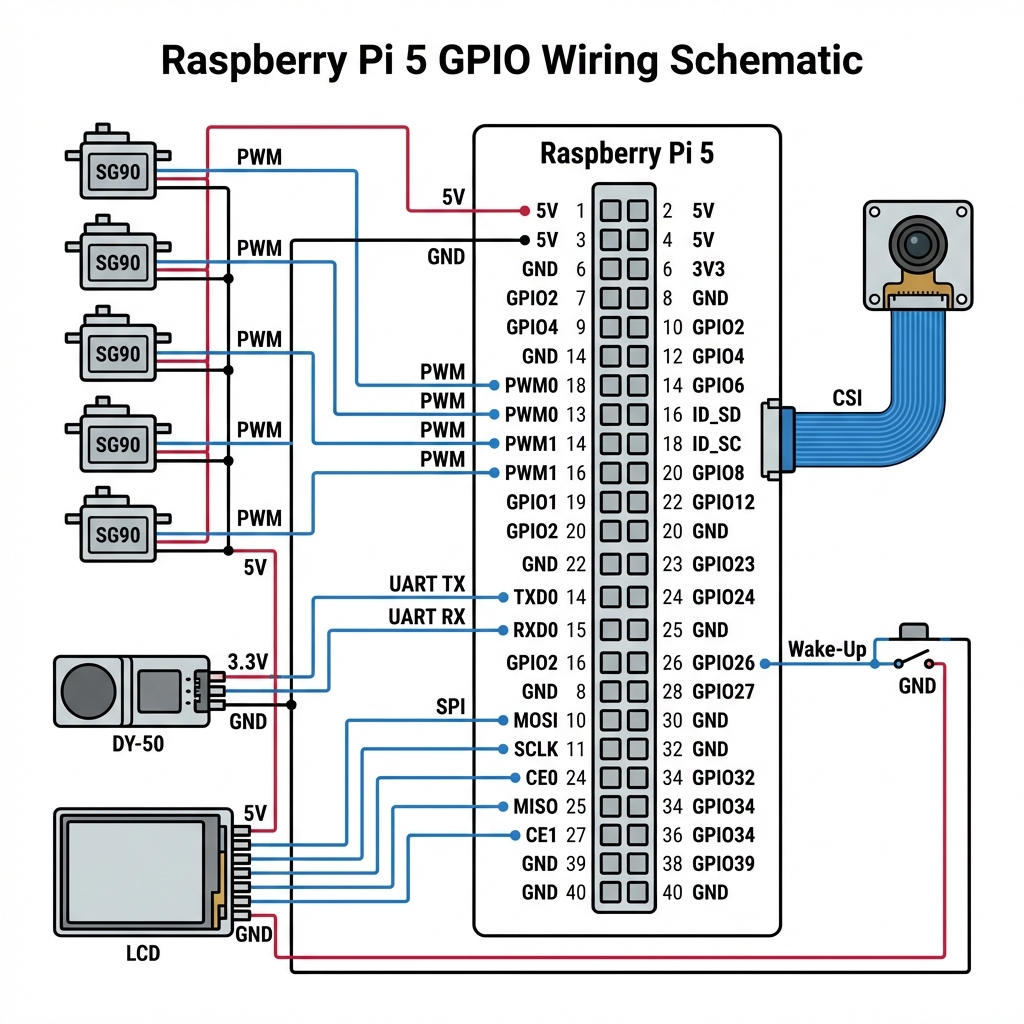
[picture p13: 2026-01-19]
docs/slides/pic/gpio_schematic.png

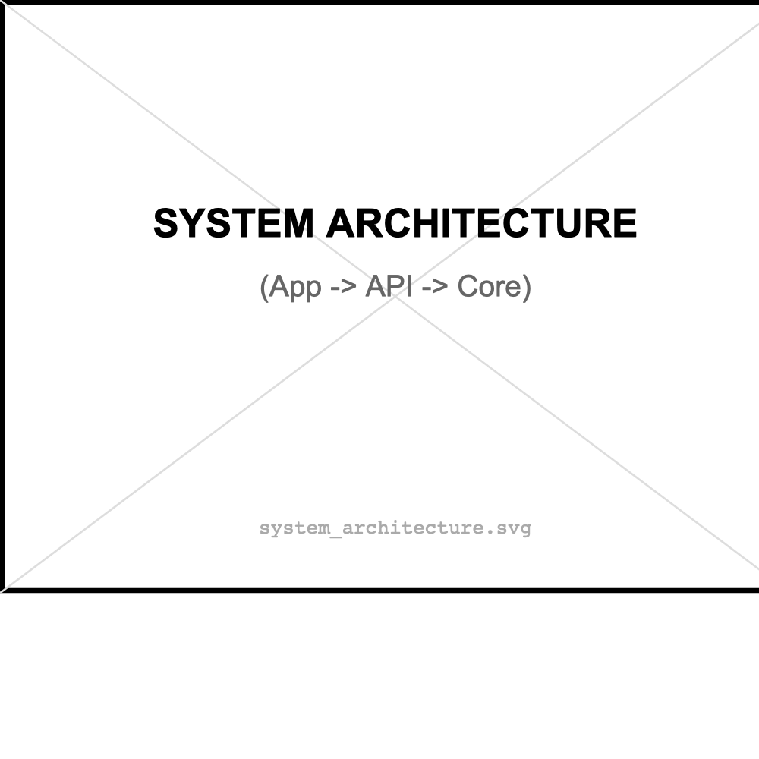
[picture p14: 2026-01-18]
docs/slides/pic/system_architecture.png

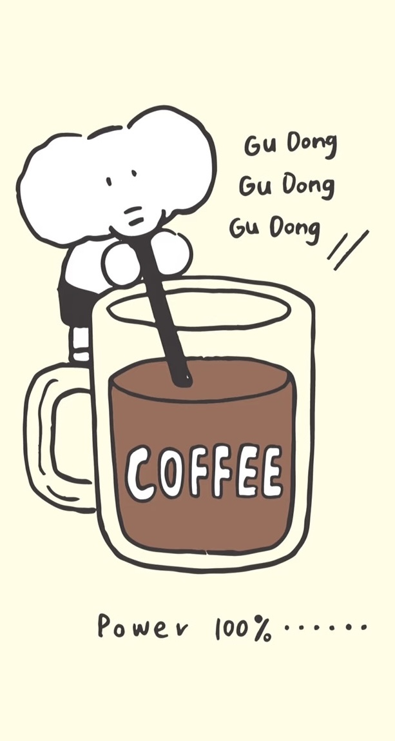
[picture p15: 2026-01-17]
android/doc/cafe2.jpg

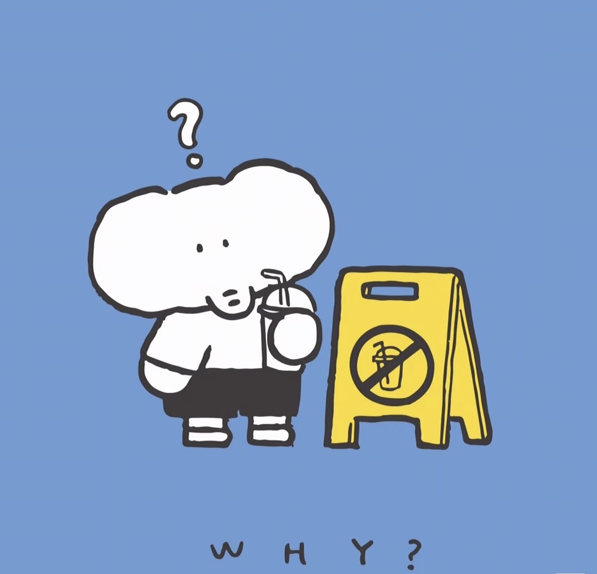
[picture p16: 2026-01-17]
android/doc/cafe.jpg

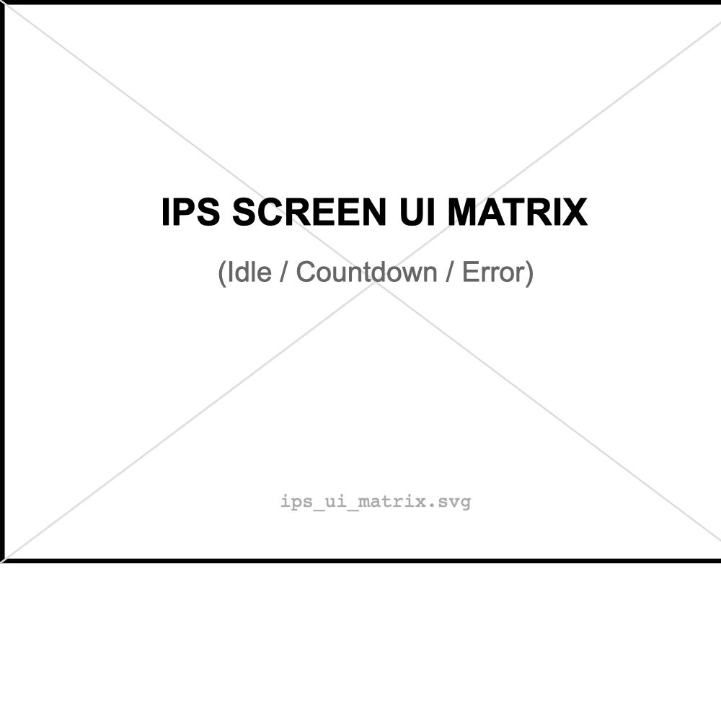
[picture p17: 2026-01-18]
docs/slides/pic/ips_ui_matrix.png

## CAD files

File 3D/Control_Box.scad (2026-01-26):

difference() {
	cube(size = [100.0, 50.0, 200.0]);
	translate(v = [3.0, 3.0, 3.0]) {
		cube(size = [94.0, 50.0, 194.0]);
	}
	translate(v = [38.5, -5, 7.0]) {
		cube(size = [23.0, 13.0, 46.0]);
	}
	translate(v = [38.0, -5, 88.0]) {
		cube(size = [24.0, 13.0, 24.0]);
	}
	translate(v = [50.0, -5, 180.0]) {
		rotate(a = [-90, 0, 0]) {
			cylinder(d = 8.0, h = 13.0);
		}
	}
	translate(v = [-5, 6, 50]) {
		rotate(a = [0, 90, 0]) {
			cylinder(d = 3.2, h = 13.0);
		}
	}
	translate(v = [-5, 6, 100]) {
		rotate(a = [0, 90, 0]) {
			cylinder(d = 3.2, h = 13.0);
		}
	}
	translate(v = [-5, 6, 150]) {
		rotate(a = [0, 90, 0]) {
			cylinder(d = 3.2, h = 13.0);
		}
	}
	translate(v = [-5, 15, 120]) {
		cube(size = [13.0, 20, 40]);
	}
	translate(v = [95.0, 15, 120]) {
		cube(size = [13.0, 20, 40]);
	}
	rotate(a = [15.0, 0, 0]) {
		translate(v = [-10, -10, -50]) {
			cube(size = [120.0, 100.0, 50]);
		}
	}
}

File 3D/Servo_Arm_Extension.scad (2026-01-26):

translate(v = [0, 0, 4.0]) {
	rotate(a = [180, 0, 0]) {
		difference() {
			union() {
				difference() {
					translate(v = [0, 11.0, 0]) {
						cylinder(d = 38.0, h = 4.0);
					}
					translate(v = [0, 0, -0.1]) {
						hull() {
							cylinder(d = 7.5, h = 3.1);
							translate(v = [0, 16.5, 0]) {
								cylinder(d = 5.5, h = 3.1);
							}
						}
					}
				}
				translate(v = [0, 0, 2.0]) {
					cylinder(d = 4.0, h = 1.1);
				}
			}
			translate(v = [0, 0, 3.5]) {
				cylinder(d = 4.0, h = 1.0);
			}
			translate(v = [0, 0, -1]) {
				cylinder(d = 2.4, h = 6.0);
			}
		}
	}
}

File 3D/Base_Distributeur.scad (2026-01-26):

difference() {
	rotate(a = [15.0, 0, 0]) {
		union() {
			translate(v = [-130.0, 0, 0]) {
				difference() {
					union() {
						difference() {
							cube(size = [260.0, 4.0, 310.0]);
							union() {
								translate(v = [19.75, -1, 271.0]) {
									cube(size = [12.5, 6.0, 33.0]);
								}
								translate(v = [71.75, -1, 271.0]) {
									cube(size = [12.5, 6.0, 33.0]);
								}
								translate(v = [123.75, -1, 271.0]) {
									cube(size = [12.5, 6.0, 33.0]);
								}
								translate(v = [175.75, -1, 271.0]) {
									cube(size = [12.5, 6.0, 33.0]);
								}
								translate(v = [227.75, -1, 271.0]) {
									cube(size = [12.5, 6.0, 33.0]);
								}
							}
						}
						translate(v = [0, 4.0, 0]) {
							difference() {
								cube(size = [260.0, 4.0, 310.0]);
								union() {
									translate(v = [6.5, -0.5, 29.5]) {
										cube(size = [39.0, 5.0, 220.5]);
									}
									translate(v = [26.0, -0.5, 29.5]) {
										rotate(a = [-90, 0, 0]) {
											cylinder($fn = 64, d = 39.0, h = 5.0);
										}
									}
									translate(v = [26.0, -0.5, 250.0]) {
										rotate(a = [-90, 0, 0]) {
											cylinder($fn = 64, d = 40.0, h = 5.0);
										}
									}
									translate(v = [58.5, -0.5, 29.5]) {
										cube(size = [39.0, 5.0, 220.5]);
									}
									translate(v = [78.0, -0.5, 29.5]) {
										rotate(a = [-90, 0, 0]) {
											cylinder($fn = 64, d = 39.0, h = 5.0);
										}
									}
									translate(v = [78.0, -0.5, 250.0]) {
										rotate(a = [-90, 0, 0]) {
											cylinder($fn = 64, d = 40.0, h = 5.0);
										}
									}
									translate(v = [110.5, -0.5, 29.5]) {
										cube(size = [39.0, 5.0, 220.5]);
									}
									translate(v = [130.0, -0.5, 29.5]) {
										rotate(a = [-90, 0, 0]) {
											cylinder($fn = 64, d = 39.0, h = 5.0);
										}
									}
									translate(v = [130.0, -0.5, 250.0]) {
										rotate(a = [-90, 0, 0]) {
											cylinder($fn = 64, d = 40.0, h = 5.0);
										}
									}
									translate(v = [162.5, -0.5, 29.5]) {
										cube(size = [39.0, 5.0, 220.5]);
									}
									translate(v = [182.0, -0.5, 29.5]) {
										rotate(a = [-90, 0, 0]) {
											cylinder($fn = 64, d = 39.0, h = 5.0);
										}
									}
									translate(v = [182.0, -0.5, 250.0]) {
										rotate(a = [-90, 0, 0]) {
											cylinder($fn = 64, d = 40.0, h = 5.0);
										}
									}
									translate(v = [214.5, -0.5, 29.5]) {
										cube(size = [39.0, 5.0, 220.5]);
									}
									translate(v = [234.0, -0.5, 29.5]) {
										rotate(a = [-90, 0, 0]) {
											cylinder($fn = 64, d = 39.0, h = 5.0);
										}
									}
									translate(v = [234.0, -0.5, 250.0]) {
										rotate(a = [-90, 0, 0]) {
											cylinder($fn = 64, d = 40.0, h = 5.0);
										}
									}
								}
								union() {
									translate(v = [19.75, -1, 276.0]) {
										cube(size = [12.5, 14.0, 23.0]);
									}
									translate(v = [26.0, -1, 301.5]) {
										rotate(a = [-90, 0, 0]) {
											cylinder($fn = 32, d = 2.0, h = 14.0);
										}
									}
									translate(v = [26.0, -1, 273.5]) {
										rotate(a = [-90, 0, 0]) {
											cylinder($fn = 32, d = 2.0, h = 14.0);
										}
									}
									translate(v = [71.75, -1, 276.0]) {
										cube(size = [12.5, 14.0, 23.0]);
									}
									translate(v = [78.0, -1, 301.5]) {
										rotate(a = [-90, 0, 0]) {
											cylinder($fn = 32, d = 2.0, h = 14.0);
										}
									}
									translate(v = [78.0, -1, 273.5]) {
										rotate(a = [-90, 0, 0]) {
											cylinder($fn = 32, d = 2.0, h = 14.0);
										}
									}
									translate(v = [123.75, -1, 276.0]) {
										cube(size = [12.5, 14.0, 23.0]);
									}
									translate(v = [130.0, -1, 301.5]) {
										rotate(a = [-90, 0, 0]) {
											cylinder($fn = 32, d = 2.0, h = 14.0);
										}
									}
									translate(v = [130.0, -1, 273.5]) {
										rotate(a = [-90, 0, 0]) {
											cylinder($fn = 32, d = 2.0, h = 14.0);
										}
									}
									translate(v = [175.75, -1, 276.0]) {
										cube(size = [12.5, 14.0, 23.0]);
									}
									translate(v = [182.0, -1, 301.5]) {
										rotate(a = [-90, 0, 0]) {
											cylinder($fn = 32, d = 2.0, h = 14.0);
										}
									}
									translate(v = [182.0, -1, 273.5]) {
										rotate(a = [-90, 0, 0]) {
											cylinder($fn = 32, d = 2.0, h = 14.0);
										}
									}
									translate(v = [227.75, -1, 276.0]) {
										cube(size = [12.5, 14.0, 23.0]);
									}
									translate(v = [234.0, -1, 301.5]) {
										rotate(a = [-90, 0, 0]) {
											cylinder($fn = 32, d = 2.0, h = 14.0);
										}
									}
									translate(v = [234.0, -1, 273.5]) {
										rotate(a = [-90, 0, 0]) {
											cylinder($fn = 32, d = 2.0, h = 14.0);
										}
									}
								}
							}
						}
						translate(v = [0, 8.0, 0]) {
							difference() {
								cube(size = [260.0, 4.0, 310.0]);
								union() {
									translate(v = [10.5, -0.5, 25.5]) {
										cube(size = [31.0, 5.0, 224.5]);
									}
									translate(v = [26.0, -0.5, 25.5]) {
										rotate(a = [-90, 0, 0]) {
											cylinder($fn = 64, d = 31.0, h = 5.0);
										}
									}
									translate(v = [62.5, -0.5, 25.5]) {
										cube(size = [31.0, 5.0, 224.5]);
									}
									translate(v = [78.0, -0.5, 25.5]) {
										rotate(a = [-90, 0, 0]) {
											cylinder($fn = 64, d = 31.0, h = 5.0);
										}
									}
									translate(v = [114.5, -0.5, 25.5]) {
										cube(size = [31.0, 5.0, 224.5]);
									}
									translate(v = [130.0, -0.5, 25.5]) {
										rotate(a = [-90, 0, 0]) {
											cylinder($fn = 64, d = 31.0, h = 5.0);
										}
									}
									translate(v = [166.5, -0.5, 25.5]) {
										cube(size = [31.0, 5.0, 224.5]);
									}
									translate(v = [182.0, -0.5, 25.5]) {
										rotate(a = [-90, 0, 0]) {
											cylinder($fn = 64, d = 31.0, h = 5.0);
										}
									}
									translate(v = [218.5, -0.5, 25.5]) {
										cube(size = [31.0, 5.0, 224.5]);
									}
									translate(v = [234.0, -0.5, 25.5]) {
										rotate(a = [-90, 0, 0]) {
											cylinder($fn = 64, d = 31.0, h = 5.0);
										}
									}
								}
								union() {
									translate(v = [26.0, -1, 250.0]) {
										rotate(a = [-90, 0, 0]) {
											cylinder($fn = 64, d = 40.0, h = 6.0);
										}
									}
									translate(v = [78.0, -1, 250.0]) {
										rotate(a = [-90, 0, 0]) {
											cylinder($fn = 64, d = 40.0, h = 6.0);
										}
									}
									translate(v = [130.0, -1, 250.0]) {
										rotate(a = [-90, 0, 0]) {
											cylinder($fn = 64, d = 40.0, h = 6.0);
										}
									}
									translate(v = [182.0, -1, 250.0]) {
										rotate(a = [-90, 0, 0]) {
											cylinder($fn = 64, d = 40.0, h = 6.0);
										}
									}
									translate(v = [234.0, -1, 250.0]) {
										rotate(a = [-90, 0, 0]) {
											cylinder($fn = 64, d = 40.0, h = 6.0);
										}
									}
								}
								union() {
									translate(v = [19.75, -1, 276.0]) {
										cube(size = [12.5, 14.0, 23.0]);
									}
									translate(v = [26.0, -1, 301.5]) {
										rotate(a = [-90, 0, 0]) {
											cylinder($fn = 32, d = 2.0, h = 14.0);
										}
									}
									translate(v = [26.0, -1, 273.5]) {
										rotate(a = [-90, 0, 0]) {
											cylinder($fn = 32, d = 2.0, h = 14.0);
										}
									}
									translate(v = [71.75, -1, 276.0]) {
										cube(size = [12.5, 14.0, 23.0]);
									}
									translate(v = [78.0, -1, 301.5]) {
										rotate(a = [-90, 0, 0]) {
											cylinder($fn = 32, d = 2.0, h = 14.0);
										}
									}
									translate(v = [78.0, -1, 273.5]) {
										rotate(a = [-90, 0, 0]) {
											cylinder($fn = 32, d = 2.0, h = 14.0);
										}
									}
									translate(v = [123.75, -1, 276.0]) {
										cube(size = [12.5, 14.0, 23.0]);
									}
									translate(v = [130.0, -1, 301.5]) {
										rotate(a = [-90, 0, 0]) {
											cylinder($fn = 32, d = 2.0, h = 14.0);
										}
									}
									translate(v = [130.0, -1, 273.5]) {
										rotate(a = [-90, 0, 0]) {
											cylinder($fn = 32, d = 2.0, h = 14.0);
										}
									}
									translate(v = [175.75, -1, 276.0]) {
										cube(size = [12.5, 14.0, 23.0]);
									}
									translate(v = [182.0, -1, 301.5]) {
										rotate(a = [-90, 0, 0]) {
											cylinder($fn = 32, d = 2.0, h = 14.0);
										}
									}
									translate(v = [182.0, -1, 273.5]) {
										rotate(a = [-90, 0, 0]) {
											cylinder($fn = 32, d = 2.0, h = 14.0);
										}
									}
									translate(v = [227.75, -1, 276.0]) {
										cube(size = [12.5, 14.0, 23.0]);
									}
									translate(v = [234.0, -1, 301.5]) {
										rotate(a = [-90, 0, 0]) {
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

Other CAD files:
3D/Base_Distributeur_backup.scad
3D/Base_Distributeur_Bottom.scad
3D/Base_Distributeur_Combined.scad
3D/Base_Distributeur_Top.scad
3D/Base_Distributeur_not_ameliore.scad
3D/Drawer.scad
3D/Drawer_patch.scad
3D/Drawer_with_patch.scad
3D/Reinforcement_Strip.scad
3D/Servo_Arm_Extension_old.scad
3D/distCapsBase_v3.scad
3D/distCapsDemo_v3.scad
3D/distCapsPushDemo_v3_handle.scad
3D/distCapsPush_v3.scad
3D/pusherHandle.scad

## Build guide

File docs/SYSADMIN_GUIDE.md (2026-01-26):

# 操作与维护手册 / Manuel d'Opération et de Maintenance

**项目名称 / Projet**: DistCapsule (Smart Capsule Dispenser)
**部署位置 / Emplacement**: 教室部署 / Salle de Classe
**版本 / Version**: 1.1 (Production)

---

## 1. 快速启动 / Démarrage Rapide

### 1.1 开机 (Mise sous tension)
*   将 **USB-C 电源 (27W)** 插入树莓派。
    *   *Brancher l'alimentation USB-C (27W) au Raspberry Pi 5.*
*   将 **外部 5V 电源 ** 插入以供电舵机。
    *   *Brancher l'alimentation externe 5V pour les moteurs.*
*   **等待 10 秒**：系统后台服务启动需要时间。
    *   *Attendre 10 secondes : Le système démarre les services.*
*   当系统准备就绪，LCD 屏幕将显示欢迎画面。
    *   *L'écran LCD affichera le message de bienvenue une fois prêt.*

### 1.2 网络连接 / Connexion Réseau

系统提供两种连接模式。
*Le système propose deux modes de connexion.*

#### A. Wi-Fi 热点模式 (App 专用) / Mode Wi-Fi (Pour App Android)
这是日常使用的默认模式。
*C'est le mode par défaut pour l'utilisation normale.*

*   **SSID (Wi-Fi名称)** : `DistCapsule_Box`
*   **密码 / Mot de passe** : `capsule_admin`
*   **网关 IP / IP du Pi** : `192.168.4.1`

#### B. 以太网模式 (维护专用) / Mode Ethernet (Pour Maintenance)
用于 SSH 远程管理或系统更新。
*Utilisez ce mode pour l'administration SSH.*

*   **固定 IP / IP Statique** : `192.168.3.14`
*   **连接方式** : 使用网线连接到交换机/路由器。
    *   *Connecter le câble Ethernet au switch/routeur.*

---

## 2. 物理交互 / Interaction Physique

### 唤醒按钮 (Bouton de Réveil)
*   **位置**: 机器**背面**，位于 **5号通道 (Canal 5)** 的后方。
    *   *Emplacement : Au **DOS** de la machine, derrière le **Canal 5**.*
*   **功能**: 当屏幕熄灭进入省电模式时，**短按一次**即可唤醒系统并点亮屏幕。
    *   *Fonction : Appuyez **une fois** pour réveiller le système et allumer l'écran lorsqu'il est en veille.*

---

## 3. 管理员访问 / Accès Administrateur

如需查看日志或维护数据库，请通过 SSH 连接。
*Pour la maintenance (logs, base de données), connectez-vous via SSH.*

### 账号信息 / Identifiants

| 服务 / Service | 用户名 / User | 密码 / Password | IP 地址 / Adresse IP |
| :--- | :--- | :--- | :--- |
| **系统 (SSH)** | `cafe` | `capsule` | `192.168.3.14` (Eth) / `192.168.4.1` (Wi-Fi) |
| **Wi-Fi 热点** | - | `capsule_admin` | - |

### SSH 连接示例 / Connexion SSH

在终端中输入 / Dans le terminal :

```bash
# 通过网线连接 / Via Ethernet (Recommandé)
ssh cafe@192.168.3.14

# 通过 Wi-Fi 连接 / Via Wi-Fi
ssh cafe@192.168.4.1
```

---

## 4. 服务管理 / Gestion des Services

### 检查状态 / Vérifier l'état
```bash
sudo systemctl status capsule      # 主程序 (Hardware)
sudo systemctl status capsule_api  # API 服务 (App)
```

### 重启系统 / Redémarrer le système
如果系统卡死或 App 无法连接：
*Si le système est figé ou l'application ne se connecte pas :*
```bash
sudo reboot
```

### 安全关机 / Arrêt Propre (Shutdown)
**拔电前请务必执行关机命令**，防止损坏 SD 卡。
*Toujours éteindre proprement avant de débrancher pour éviter la corruption de la carte SD.*
```bash
sudo shutdown -h now
```

---

## 5. 数据库维护 / Dépannage Base de Données

如果需要紧急恢复管理员权限或重置通道状态。
*Commandes SQL d'urgence pour restaurer l'admin ou libérer un canal.*

**1. 进入数据库 / Entrer SQL Console**
```bash
cd ~/DistCapsule
sqlite3 capsule_dispenser.db
```

**2. 紧急恢复管理员 / Restauration Admin**
如果不小心删除了唯一的管理员 (ID 1) / *Si le compte admin a été supprimé* :
```sql
UPDATE Users SET auth_level=1 WHERE user_id=1;
```

**3. 释放卡住的通道 / Libérer un canal bloqué**
如果通道 1 显示被占用但实际上无人使用 / *Si le canal 1 est bloqué* :
```sql
UPDATE Users SET assigned_channel=NULL WHERE assigned_channel=1;
```

**4. 退出 / Quitter**
```sql
.quit
```

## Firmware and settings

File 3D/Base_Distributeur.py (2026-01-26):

from solid2 import *
import os
import math

# --- Amazon Product Replica Parameters (MOLEDINO) ---
# Dimensions: 32L x 26W x 1.2H cm -> Increased Height for Servo
TOTAL_WIDTH = 260.0
TOTAL_HEIGHT = 310.0
TOTAL_THICKNESS = 12.0

# Layer Thicknesses (Total 12mm)
# Structure: Back Plate + Rail Layer + Front Plate
BACK_THICKNESS = 4.0
RAIL_THICKNESS = 4.0   # Space for capsule rim (approx 1mm rim + clearance + tilt)
FRONT_THICKNESS = 4.0

# Nespresso Original Capsule Dimensions
CAPSULE_BODY_DIAM = 30.0
CAPSULE_RIM_DIAM = 37.0

# Design Tolerances
SLOT_WIDTH = 31.0       # Allows body (30mm) to pass, catches rim (37mm)
TRACK_WIDTH = 39.0      # Allows rim (37mm) to slide freely
ENTRY_HOLE_DIAM = 40.0  # Allows rim to be inserted from front
TOP_MARGIN = 60.0       # Distance from top edge to center of entry hole
BOTTOM_MARGIN = 10.0    # Distance from bottom edge to bottom of the slot

NUM_COLUMNS = 5
COLUMN_WIDTH = TOTAL_WIDTH / NUM_COLUMNS

# Tilt and Stand Parameters
TILT_ANGLE = 15.0       # Degrees to tilt back
STAND_DEPTH = 80.0      # How far back the stand extends (on the ground)
STAND_THICKNESS = 10.0  # Thickness of the stand legs

# Servo SG90 Parameters
SERVO_WIDTH = 23.0      # Width of the servo body (horizontal)
SERVO_HEIGHT = 12.5     # Thickness of the servo body (vertical in this orientation?)
                        # Standard SG90: 22.5 x 12.5 x 22.5 mm
                        # We will mount it such that the arm rotates in the XY plane (blocking the channel)
                        # So the servo axis is along Z (perpendicular to back plate)? 
                        # No, servo axis should be perpendicular to the plate (Y axis in our model coordinates before tilt)
                        # So the arm sweeps across the track.
SERVO_BODY_W = 23.0
SERVO_BODY_H = 23.0
SERVO_BODY_D = 12.5     # Depth (thickness)

# Servo Position
# User requested to move the servo UP so it doesn't overlap with the entry hole.
# Entry hole center is at TOTAL_HEIGHT - TOP_MARGIN (310). Radius 20 -> Top at 330.
# We place the servo shaft at 345 (15mm above the hole).
SERVO_Z_POS = 345.0
# Servo Offset: Keep it to the side (22mm)
SERVO_X_OFFSET = 22.0 

def create_replica(part="all"):
    # 1. Back Plate (Solid)
    # Position: Y = 0 to 4
    back_plate_block = cube([TOTAL_WIDTH, BACK_THICKNESS, TOTAL_HEIGHT])
    
    # 2. Middle Rail Layer (Tracks)
    # Position: Y = 4 to 8
    rail_block = cube([TOTAL_WIDTH, RAIL_THICKNESS, TOTAL_HEIGHT])
    
    tracks = []
    
    # Separate cutout lists for each layer to create the "recessed" mounting
    back_cutouts = []
    rail_cutouts = []
    front_cutouts = []
    
    for i in range(NUM_COLUMNS):
        cx = (i * COLUMN_WIDTH) + (COLUMN_WIDTH / 2)
        
        # --- Track Geometry ---
        track_radius = TRACK_WIDTH / 2.0
        
        # A. Rectangular part
        rect_start_z = BOTTOM_MARGIN + track_radius
        rect_height = (TOTAL_HEIGHT - TOP_MARGIN) - rect_start_z
        
        track_rect = cube([TRACK_WIDTH, RAIL_THICKNESS + 1, rect_height])
        track_rect = translate([cx - TRACK_WIDTH/2, -0.5, rect_start_z])(track_rect)
        tracks.append(track_rect)
        
        # B. Circular Bottom
        track_circle = cylinder(d=TRACK_WIDTH, h=RAIL_THICKNESS + 1, _fn=64)
        track_circle = rotate([-90, 0, 0])(track_circle)
        track_circle = translate([cx, -0.5, rect_start_z])(track_circle)
        tracks.append(track_circle)
        
        # C. Entry Clearance (Top)
        entry_clearance = cylinder(d=ENTRY_HOLE_DIAM, h=RAIL_THICKNESS + 1, _fn=64)
        entry_clearance = rotate([-90, 0, 0])(entry_clearance)
        entry_clearance = translate([cx, -0.5, TOTAL_HEIGHT - TOP_MARGIN])(entry_clearance)
        tracks.append(entry_clearance)
        
        # --- Servo Mounting (Recessed) ---
        # Goal: Sink the servo into the Back Plate so the ears rest on the Rail Layer.
        # This allows the shaft to protrude further to the front.
        
        # Dimensions
        sg90_w = 12.5
        sg90_h_body = 23.0
        sg90_h_ears = 33.0  # Total length including flanges
        
        # Position (Above hole)
        hole_top_z = (TOTAL_HEIGHT - TOP_MARGIN) + (ENTRY_HOLE_DIAM / 2.0)
        margin = 6.0
        servo_bottom_z = hole_top_z + margin
        
        # 1. Body Cutout (Small) - Goes through Rail and Front
        # Positioned at servo_bottom_z
        c_body = cube([sg90_w, TOTAL_THICKNESS + 2, sg90_h_body])
        c_body = translate([cx - sg90_w/2, -1, servo_bottom_z])(c_body)
        
        rail_cutouts.append(c_body)
        front_cutouts.append(c_body)
        
        # 2. Ears Cutout (Large) - Goes through Back Plate ONLY
        # Centered on the body cutout, but taller
        # Center Z of body = servo_bottom_z + sg90_h_body/2
        center_z = servo_bottom_z + sg90_h_body/2
        
        c_ears = cube([sg90_w, BACK_THICKNESS + 2, sg90_h_ears])
        # Align center Z
        c_ears = translate([cx - sg90_w/2, -1, center_z - sg90_h_ears/2])(c_ears)
        
        back_cutouts.append(c_ears)
        
        # 3. Screw Holes - Go through Rail and Front (for mounting)
        # Located at the "ears" position (top and bottom of the body)
        # Screw distance approx 28mm apart (center to center)
        screw_dist = 28.0
        
        s_top = cylinder(d=2.0, h=TOTAL_THICKNESS + 2, _fn=32)
        s_top = rotate([-90, 0, 0])(s_top)
        s_top = translate([cx, -1, center_z + screw_dist/2])(s_top)
        
        s_bot = cylinder(d=2.0, h=TOTAL_THICKNESS + 2, _fn=32)
        s_bot = rotate([-90, 0, 0])(s_bot)
        s_bot = translate([cx, -1, center_z - screw_dist/2])(s_bot)
        
        rail_cutouts.append(s_top)
        rail_cutouts.append(s_bot)
        front_cutouts.append(s_top)
        front_cutouts.append(s_bot)

    # Apply tracks to rail layer
    if tracks:
        rail_block -= union()(*tracks)

    # Apply Layer-Specific Cutouts
    if back_cutouts:
        back_plate_block -= union()(*back_cutouts)
        
    if rail_cutouts:
        rail_block -= union()(*rail_cutouts)
        
    rail_layer = translate([0, BACK_THICKNESS, 0])(rail_block)


    # 3. Front Plate (Slots + Entry Holes)
    # Position: Y = 8 to 12
    front_block = cube([TOTAL_WIDTH, FRONT_THICKNESS, TOTAL_HEIGHT])
    
    slots = []
    entries = []
    
    for i in range(NUM_COLUMNS):
        cx = (i * COLUMN_WIDTH) + (COLUMN_WIDTH / 2)
        
        # Slot Geometry
        slot_radius = SLOT_WIDTH / 2.0
        
        # A. Rectangular part
        rect_start_z = BOTTOM_MARGIN + slot_radius
        rect_height = (TOTAL_HEIGHT - TOP_MARGIN) - rect_start_z
        
        slot_rect = cube([SLOT_WIDTH, FRONT_THICKNESS + 1, rect_height])
        slot_rect = translate([cx - SLOT_WIDTH/2, -0.5, rect_start_z])(slot_rect)
        slots.append(slot_rect)
        
        # B. Circular Bottom
        slot_circle = cylinder(d=SLOT_WIDTH, h=FRONT_THICKNESS + 1, _fn=64)
        slot_circle = rotate([-90, 0, 0])(slot_circle)
        slot_circle = translate([cx, -0.5, rect_start_z])(slot_circle)
        slots.append(slot_circle)
        
        # C. Entry Hole (Top)
        entry = cylinder(d=ENTRY_HOLE_DIAM, h=FRONT_THICKNESS + 2, _fn=64)
        entry = rotate([-90, 0, 0])(entry)
        entry = translate([cx, -1, TOTAL_HEIGHT - TOP_MARGIN])(entry)
        entries.append(entry)
        
    if slots:
        front_block -= union()(*slots)
    if entries:
        front_block -= union()(*entries)
        
    # Apply servo cutouts to front plate (Through Hole)
    if front_cutouts:
        front_block -= union()(*front_cutouts)

    front_layer = translate([0, BACK_THICKNESS + RAIL_THICKNESS, 0])(front_block)

    # --- Base Filler ---
    # Fill the wedge gap under the body (Y=0 to 12) caused by the 15 deg tilt.
    # We simply extend the body downwards. The excess will be cut globally in the main block.
    filler_block = cube([TOTAL_WIDTH, TOTAL_THICKNESS, 50])
    filler_block = translate([0, 0, -50])(filler_block)
    
    # Return specific part if requested
    if part == "front":
        return translate([-TOTAL_WIDTH/2, 0, 0])(front_block)
    elif part == "rail":
        return translate([-TOTAL_WIDTH/2, 0, 0])(rail_block)
    elif part == "back":
        return translate([-TOTAL_WIDTH/2, 0, 0])(back_plate_block)

    # 4. Combine into one object
    assembly = back_plate_block + rail_layer + front_layer + filler_block
    
    # --- Rounded Corners (Top Left & Top Right) ---
    CORNER_RADIUS = 15.0
    EPS = 1.0 # Extra margin to ensure clean cuts
    
    # Cutter for Top-Left (X=0)
    # Block covers [-EPS, R] in X, [H-R, H+EPS] in Z
    tl_block = cube([CORNER_RADIUS + EPS, TOTAL_THICKNESS + 20, CORNER_RADIUS + EPS])
    tl_block = translate([-EPS, -10, TOTAL_HEIGHT - CORNER_RADIUS])(tl_block)
    
    tl_cyl = cylinder(r=CORNER_RADIUS, h=TOTAL_THICKNESS + 20, _fn=64)
    tl_cyl = rotate([-90, 0, 0])(tl_cyl) # Axis along Y
    tl_cyl = translate([CORNER_RADIUS, -10, TOTAL_HEIGHT - CORNER_RADIUS])(tl_cyl)
    
    tl_cutter = tl_block - tl_cyl
    
    # Cutter for Top-Right (X=TOTAL_WIDTH)
    # Block covers [W-R, W+EPS] in X, [H-R, H+EPS] in Z
    tr_block = cube([CORNER_RADIUS + EPS, TOTAL_THICKNESS + 20, CORNER_RADIUS + EPS])
    tr_block = translate([TOTAL_WIDTH - CORNER_RADIUS, -10, TOTAL_HEIGHT - CORNER_RADIUS])(tr_block)
    
    tr_cyl = cylinder(r=CORNER_RADIUS, h=TOTAL_THICKNESS + 20, _fn=64)
    tr_cyl = rotate([-90, 0, 0])(tr_cyl)
    tr_cyl = translate([TOTAL_WIDTH - CORNER_RADIUS, -10, TOTAL_HEIGHT - CORNER_RADIUS])(tr_cyl)
    
    tr_cutter = tr_block - tr_cyl
    
    assembly = assembly - tl_cutter - tr_cutter
    
    # --- Sidecar Mounting Holes (Right Side) ---
    # Holes on the rightmost edge to attach the Control Box
    # Located on the Bottom Half (< 190mm)
    # Adjusted to fit in the 6.5mm solid margin on the right edge.
    
    # Center on X axis for better preview
    assembly = translate([-TOTAL_WIDTH/2, 0, 0])(assembly)
    
    return assembly

def create_integrated_legs():
    """
    Generates a 'Picture Frame' style stand.
    Two legs at the extreme edges, connected by a bar at the bottom.
    """
    LEG_THICK = 15.0
    STAND_DEPTH = 90.0 # Depth on the ground
    
    # 1. Create the raw block for the stand (Legs + Crossbar)
    # Height reduced to 0.6 * TOTAL_HEIGHT
    
    # Left Leg Block (Positive X - User Left)
    leg_l = cube([LEG_THICK, STAND_DEPTH, TOTAL_HEIGHT * 0.6])
    leg_l = translate([TOTAL_WIDTH/2 - LEG_THICK, -STAND_DEPTH, 0])(leg_l)
    
    # Right Leg Block (Negative X - User Right)
    leg_r = cube([LEG_THICK, STAND_DEPTH, TOTAL_HEIGHT * 0.6])
    leg_r = translate([-TOTAL_WIDTH/2, -STAND_DEPTH, 0])(leg_r)
    
    # --- Sidecar Mounting Holes (Right Leg / Negative X) ---
    # Holes on the Right Leg (Negative X) to attach the Control Box
    
    sidecar_holes = []
    SIDECAR_HOLE_DIAM = 3.2 # M3
    
    # 1. Vertical Column at Y = -8.0
    # Bottom hole at 15.6 (Stand Frame) to match locking hole height (13.0) in Final Frame
    col_y = -8.0
    col_zs = [15.6, 65.6, 115.6]
    
    for z in col_zs:
        sh = cylinder(d=SIDECAR_HOLE_DIAM, h=LEG_THICK + 20, _fn=32)
        sh = rotate([0, 90, 0])(sh)
        sh = translate([-TOTAL_WIDTH/2 - 10, col_y, z])(sh)
        sidecar_holes.append(sh)
        
    # 2. Horizontal Row (aligned with bottom hole)
    # Spacing 20mm backwards. Z adjusted to maintain horizontal level in tilted view.
    # Hole 2: Y=-28.0, Z=21.0
    # Hole 3: Y=-48.0, Z=26.3
    extra_holes = [(-28.0, 21.0), (-48.0, 26.3)]
    
    for (y, z) in extra_holes:
        sh = cylinder(d=SIDECAR_HOLE_DIAM, h=LEG_THICK + 20, _fn=32)
        sh = rotate([0, 90, 0])(sh)
        sh = translate([-TOTAL_WIDTH/2 - 10, y, z])(sh)
        sidecar_holes.append(sh)
        
    # --- Leg Extension for Counterbore ---
    # We need to extend the legs backwards at the bottom to accommodate the counterbore.
    # Extension: 2mm deep, enough height to cover the step.
    EXT_DEPTH = 2.0
    EXT_HEIGHT = 50.0 # Arbitrary high enough, will be trimmed by slope_cutter
    
    ext_block = cube([LEG_THICK, EXT_DEPTH, EXT_HEIGHT])
    
    # Left Extension (Positive X)
    ext_l = translate([TOTAL_WIDTH/2 - LEG_THICK, -STAND_DEPTH - EXT_DEPTH, 0])(ext_block)
    leg_l += ext_l
    
    # Right Extension (Negative X)
    ext_r = translate([-TOTAL_WIDTH/2, -STAND_DEPTH - EXT_DEPTH, 0])(ext_block)
    leg_r += ext_r
    
    # --- Drawer Locking Holes (Screw Holes) ---
    # User requested holes on the side of the legs to fix the drawer.
    # Drawer is tilted by -15 deg.
    # Drawer Back Plate Center in Drawer Frame:
    # Y_d = -STAND_DEPTH + (5.0 / 2.0) = -90 + 2.5 = -87.5
    # Z_d = 10.0 (Middle of 20mm height)
    # Z_offset = CLEARANCE_H = 3.0
    
    CLEARANCE_H = 3.0
    
    # Transform to Stand Frame (Rotate -15 deg around X)
    # y_s = y_d * cos(theta) - (z_d + z_offset) * sin(theta)
    # z_s = y_d * sin(theta) + (z_d + z_offset) * cos(theta)
    
    y_d = -STAND_DEPTH + 2.5
    z_d_total = 10.0 + CLEARANCE_H
    theta_rad = math.radians(-TILT_ANGLE)
    
    y_s = y_d * math.cos(theta_rad) - z_d_total * math.sin(theta_rad)
    z_s = y_d * math.sin(theta_rad) + z_d_total * math.cos(theta_rad)
    
    y_s = round(y_s, 2)
    z_s = round(z_s, 2)
    
    LOCK_HOLE_DIAM = 2.2 # M2 Clearance
    CB_DIAM = 4.5 # M2 Head approx 3.8mm
    CB_DEPTH = 4.0 # Depth of the counterbore
    
    # Left Leg Hole (Positive X)
    # 1. Through Hole
    lock_hole_l = cylinder(d=LOCK_HOLE_DIAM, h=LEG_THICK + 20, _fn=32)
    lock_hole_l = rotate([0, 90, 0])(lock_hole_l)
    lock_hole_l = translate([TOTAL_WIDTH/2 - LEG_THICK - 10, y_s, z_s])(lock_hole_l)
    
    # 2. Counterbore (From Right/Outside of the Left Leg)
    # Leg Right Face is at X = TOTAL_WIDTH/2
    # Cut from X = TOTAL_WIDTH/2 - CB_DEPTH to TOTAL_WIDTH/2 + 10
    cb_l = cylinder(d=CB_DIAM, h=CB_DEPTH + 10, _fn=32)
    cb_l = rotate([0, 90, 0])(cb_l)
    cb_l = translate([TOTAL_WIDTH/2 - CB_DEPTH, y_s, z_s])(cb_l)
    
    # Right Leg Hole (Negative X)
    # 1. Through Hole
    lock_hole_r = cylinder(d=LOCK_HOLE_DIAM, h=LEG_THICK + 20, _fn=32)
    lock_hole_r = rotate([0, 90, 0])(lock_hole_r)
    lock_hole_r = translate([-TOTAL_WIDTH/2 - 10, y_s, z_s])(lock_hole_r)
    
    # 2. Counterbore (From Left/Outside of the Right Leg)
    # Leg Left Face is at X = -TOTAL_WIDTH/2
    # Cut from X = -TOTAL_WIDTH/2 - 10 to -TOTAL_WIDTH/2 + CB_DEPTH
    cb_r = cylinder(d=CB_DIAM, h=CB_DEPTH + 10, _fn=32)
    cb_r = rotate([0, 90, 0])(cb_r)
    cb_r = translate([-TOTAL_WIDTH/2 - 10, y_s, z_s])(cb_r)
    
    # --- Cable Management Slots (Right Leg / Negative X) ---
    # 3 Cross Slots: 15mm x 15mm overall
    # Y = -35.0 (Center -45 + 10)
    # Z = 40, 60, 80
    
    SLOT_H = 15.0
    SLOT_W = 5.0
    SLOT_Y = -STAND_DEPTH / 2.0 + 10.0 # Shifted 10mm forward from center
    SLOT_ZS = [40.0, 60.0, 80.0]
    
    # Create Vertical Slot
    c_top = cylinder(d=SLOT_W, h=LEG_THICK + 20, _fn=32)
    c_top = rotate([0, 90, 0])(c_top)
    c_top = translate([0, 0, (SLOT_H - SLOT_W)/2])(c_top)
    
    c_bot = cylinder(d=SLOT_W, h=LEG_THICK + 20, _fn=32)
    c_bot = rotate([0, 90, 0])(c_bot)
    c_bot = translate([0, 0, -(SLOT_H - SLOT_W)/2])(c_bot)
    
    vert_slot = hull()(c_top, c_bot)
    
    # Create Horizontal Slot (Rotate vertical by 90 deg around X)
    horiz_slot = rotate([90, 0, 0])(vert_slot)
    
    cross_slot = vert_slot + horiz_slot
    
    # Apply to Right Leg (leg_r) - Negative X
    slot_x = -TOTAL_WIDTH/2 - 10
    
    cable_slots = []
    for z_pos in SLOT_ZS:
        s = translate([slot_x, SLOT_Y, z_pos])(cross_slot)
        cable_slots.append(s)

    # --- Apply All Cuts ---
    
    # Left Leg Cuts
    leg_l_cuts = [lock_hole_l, cb_l]
    leg_l -= union()(*leg_l_cuts)
    
    # Right Leg Cuts
    leg_r_cuts = sidecar_holes + [lock_hole_r, cb_r] + cable_slots
    leg_r -= union()(*leg_r_cuts)

    raw_stand = leg_l + leg_r
    
    # 2. Cut the shape to be triangular
    
    # B. Cut the Back/Inside to make it a frame
    # We want a triangular profile from the side.
    # Top point: Y=0, Z = TOTAL_HEIGHT * 0.6
    # Bottom back point: Y=-STAND_DEPTH, Z = 20mm (Crossbar height)
    
    leg_height = TOTAL_HEIGHT * 0.6
    bar_height = 20.0
    
    # Calculate angle dynamically
    # tan(angle) = opposite / adjacent = (leg_height - bar_height) / STAND_DEPTH
    cut_angle = math.degrees(math.atan((leg_height - bar_height) / STAND_DEPTH))
    cut_angle = round(cut_angle, 2)
    
    slope_cutter = cube([TOTAL_WIDTH + 50, 400, 400])
    # Rotate so the bottom face becomes the slope
    # We want to keep what is BELOW the slope.
    # If we rotate by +cut_angle, the bottom face tilts up-forward.
    slope_cutter = rotate([cut_angle, 0, 0])(slope_cutter)
    
    # Position the cutter so its bottom-back edge touches the crossbar top
    # Target point: Y = -STAND_DEPTH, Z = 20
    slope_cutter = translate([-(TOTAL_WIDTH+50)/2, -STAND_DEPTH, 20])(slope_cutter)
    
    # --- Step Protector ---
    # User requested a "step" at the back to ensure the locking hole has enough material.
    # This step should match the drawer back plate shape (tilted -15 deg).
    # We subtract this "step shape" from the slope_cutter, so the cutter DOES NOT cut this area.
    # We also need to extend it downwards to fill the gap between the slope line and the ground.
    
    STEP_DEPTH = 15.0 + 2.0 # Cover the back plate (5mm) + margin + hole area + EXTENSION
    
    # Calculate height to cover from bottom (-20) to top (CLEARANCE_H + 25)
    MASK_Z_START = -20.0
    MASK_Z_TOP = CLEARANCE_H + 25.0
    STEP_HEIGHT = MASK_Z_TOP - MASK_Z_START
    
    step_mask = cube([TOTAL_WIDTH + 60, STEP_DEPTH, STEP_HEIGHT])
    # Position at the back, aligned with the groove/drawer
    # Start at Y = -STAND_DEPTH - 2.0 (Extension start)
    step_mask = translate([-(TOTAL_WIDTH+60)/2, -STAND_DEPTH - 2.0, MASK_Z_START])(step_mask)
    # Rotate to match drawer tilt
    step_mask = rotate([-TILT_ANGLE, 0, 0])(step_mask)
    
    # Modify the cutter
    final_slope_cutter = slope_cutter - step_mask
    
    final_stand = raw_stand - final_slope_cutter
    
    return final_stand

if __name__ == "__main__":
    # 1. Create the Main Body (Vertical)
    body = create_replica()
    
    # 2. Create the Integrated Stand (Vertical, pre-cut)
    stand = create_integrated_legs()
    
    # 3. Combine them
    full_model = body + stand
    
    # 4. Rotate the entire assembly by 15 degrees
    # This makes the body tilt back, and the stand's bottom (which was cut at 15 deg) become flat.
    final_model = rotate([TILT_ANGLE, 0, 0])(full_model)
    
    # 4.5. Global Groove Cut (Horizontal)
    # Cut the drawer grooves horizontally after rotation.
    LEG_THICK = 15.0
    GROOVE_H = 4.0
    GROOVE_D = 2.5
    CLEARANCE_H = 3.0
    EXTRA_CUT = 0.1 # Extra width to ensure clean cut on the open side
    GROOVE_STOP_Y = -2.0 # Stop before hitting the main body (Y=0)
    
    # Calculate Groove Length
    # Start far back (-200) and stop at GROOVE_STOP_Y
    GROOVE_START_Y = -200.0
    GROOVE_LEN = GROOVE_STOP_Y - GROOVE_START_Y
    
    # Left Groove (Positive X)
    # Inner face of left leg is at X = TOTAL_WIDTH/2 - LEG_THICK
    # We want to cut from (Face - EXTRA) to (Face + GROOVE_D)
    g_left = cube([GROOVE_D + EXTRA_CUT, GROOVE_LEN, GROOVE_H])
    g_left = translate([TOTAL_WIDTH/2 - LEG_THICK - EXTRA_CUT, GROOVE_START_Y, CLEARANCE_H])(g_left)
    
    # Right Groove (Negative X)
    # Inner face of right leg is at X = -TOTAL_WIDTH/2 + LEG_THICK
    # We want to cut from (Face - GROOVE_D) to (Face + EXTRA)
    g_right = cube([GROOVE_D + EXTRA_CUT, GROOVE_LEN, GROOVE_H])
    g_right = translate([-TOTAL_WIDTH/2 + LEG_THICK - GROOVE_D, GROOVE_START_Y, CLEARANCE_H])(g_right)
    
    final_model = final_model - g_left - g_right
    
    # 5. Global Ground Cut
    # Cut everything below Z=0 to ensure a perfectly flat base.
    # This handles the body filler and any other protrusions.
    ground_cut_box = cube([TOTAL_WIDTH + 100, STAND_DEPTH + 200, 100])
    ground_cut_box = translate([-(TOTAL_WIDTH+100)/2, -STAND_DEPTH - 100, -100])(ground_cut_box)
    
    final_model -= ground_cut_box
    
    script_dir = os.path.dirname(os.path.abspath(__file__))
    
    # Save Full Model
    file_path = os.path.join(script_dir, "Base_Distributeur.scad")
    final_model.save_as_scad(file_path)
    print(f"Generated: {file_path}")

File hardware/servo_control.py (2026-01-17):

import lgpio
import time
import sys

# 映射逻辑编号 (Servo 1-5) 到 BCM GPIO 编号 (Pi 5)
# 遵循 docs/WIRING_GUIDE.md
CHANNEL_TO_PIN = {
    1: 18, # Servo 1 (Pin 12)
    2: 6,  # Servo 2 (Pin 31)
    3: 12, # Servo 3 (Pin 32)
    4: 13, # Servo 4 (Pin 33)
    5: 19  # Servo 5 (Pin 35)
}

class ServoController:
    """
    使用 lgpio (软件 PWM) 控制 SG90 舵机。
    完全绕过硬件 PWM 限制，解决与风扇的冲突。
    """
    def __init__(self, channel):
        self.pin = CHANNEL_TO_PIN.get(channel, channel)
        # Pi 5 的 GPIO 通常在 chip 4
        try:
            self.h = lgpio.gpiochip_open(4)
        except:
            # Fallback for older Pis or different configs
            self.h = lgpio.gpiochip_open(0)
        
        try:
            lgpio.gpio_claim_output(self.h, self.pin)
        except Exception as e:
            # 如果已经被占用，打印警告但继续尝试运行
            print(f"Warning: GPIO {self.pin} already claimed or busy: {e}")

        # SG90 参数
        self.FREQ = 50 # 50Hz
        # 0度 = 0.5ms / 20ms = 2.5%
        # 180度 = 2.5ms / 20ms = 12.5%
        self.DUTY_LOCK = 2.5
        self.DUTY_UNLOCK = 12.5

    def _set_pwm(self, duty_percent):
        """设置 PWM 占空比 (0-100)"""
        lgpio.tx_pwm(self.h, self.pin, self.FREQ, duty_percent)

    def lock(self):
        """转动到锁定位置 (0度)"""
        self._set_pwm(self.DUTY_LOCK)
        time.sleep(0.5) # 等待转动
        # 关闭 PWM 以消除抖动并省电
        lgpio.tx_pwm(self.h, self.pin, 0, 0)

    def unlock(self):
        """转动到解锁位置 (180度)"""
        self._set_pwm(self.DUTY_UNLOCK)
        time.sleep(0.5)
        lgpio.tx_pwm(self.h, self.pin, 0, 0)

    def cleanup(self):
        lgpio.gpiochip_close(self.h)

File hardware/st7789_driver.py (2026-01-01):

import time
import spidev  # Python 的 SPI 接口库，用于和屏幕高速通信
import RPi.GPIO as GPIO # 树莓派 GPIO 控制库
import numpy as np # 强大的数学库，这里用来做大规模的像素矩阵计算
from PIL import Image

class ST7789_Driver:
    """
    ST7789 屏幕底层驱动类
    这个类演示了如何不依赖高级库，直接通过发送十六进制指令(Hex Codes)来控制硬件。
    """
    def __init__(self, dc=24, rst=25, blk=27, spi_port=0, spi_device=0, speed_hz=24000000):
        # 1. 硬件引脚定义 (BCM 编号)
        self.dc_pin = dc   # Data/Command: 高电平发数据，低电平发命令
        self.rst_pin = rst # Reset: 复位引脚
        self.blk_pin = blk # Backlight: 背光控制
        self.width = 240
        self.height = 240
        
        # 2. GPIO 初始化
        GPIO.setmode(GPIO.BCM)
        GPIO.setwarnings(False)
        GPIO.setup(self.dc_pin, GPIO.OUT)
        GPIO.setup(self.rst_pin, GPIO.OUT)
        GPIO.setup(self.blk_pin, GPIO.OUT)
        
        # 3. SPI 总线初始化
        # SPI 是一种同步串行通信协议，像一条高速公路
        self.spi = spidev.SpiDev()
        self.spi.open(spi_port, spi_device) # 打开 /dev/spidev0.0
        self.spi.max_speed_hz = speed_hz    # 设定速度 24MHz
        self.spi.mode = 0b11 # Mode 3 (CPOL=1, CPHA=1): 这是 ST7789 要求的通信模式
        
        self.init_display()
        
    def send_cmd(self, cmd):
        """发送命令 (DC引脚置低)"""
        GPIO.output(self.dc_pin, GPIO.LOW)
        self.spi.writebytes([cmd])

    def send_data(self, data):
        """发送数据 (DC引脚置高)"""
        GPIO.output(self.dc_pin, GPIO.HIGH)
        if isinstance(data, list) or isinstance(data, tuple):
            self.spi.writebytes(list(data))
        else:
            self.spi.writebytes([data])

    def init_display(self):
        """屏幕上电初始化流程 (Datasheet 规定的标准动作)"""
        # 1. 硬件复位 (Reset)
        # 拉高 -> 拉低(保持一会) -> 拉高，相当于按了一下重启键
        GPIO.output(self.blk_pin, GPIO.HIGH)
        GPIO.output(self.rst_pin, GPIO.HIGH)
        time.sleep(0.01)
        GPIO.output(self.rst_pin, GPIO.LOW)
        time.sleep(0.01)
        GPIO.output(self.rst_pin, GPIO.HIGH)
        time.sleep(0.15)
        
        # 2. 发送魔法指令 (Magic Codes)
        # 这些十六进制数字可以在 ST7789 芯片的数据手册(Datasheet)里查到
        self.send_cmd(0x11) # Sleep Out: 唤醒屏幕
        time.sleep(0.12)
        self.send_cmd(0x36) # MADCTL (Memory Data Access Control): 设置屏幕旋转方向
        self.send_data(0x00) 
        self.send_cmd(0x3A) # COLMOD (Interface Pixel Format): 设置颜色格式
        self.send_data(0x05) # 0x05 代表 16-bit/pixel (RGB565格式)
        self.send_cmd(0x21) # Inversion On: 反色显示 (解决某些屏幕颜色不对的问题)
        self.send_cmd(0x29) # Display On: 开启显示
        time.sleep(0.05)

    def set_window(self, x0, y0, x1, y1):
        """设定接下来要写入像素的矩形区域"""
        # x0 >> 8 是位运算"右移"，取出高8位。 x0 & 0xFF 是"按位与"，取出低8位。
        # 因为 SPI 每次只能发 8位(1字节)，而坐标可能是 240 (需要多于8位)，所以要拆开发。
        self.send_cmd(0x2A) # Column Addr (列地址)
        self.send_data([x0 >> 8, x0 & 0xFF, x1 >> 8, x1 & 0xFF])
        self.send_cmd(0x2B) # Row Addr (行地址)
        self.send_data([y0 >> 8, y0 & 0xFF, y1 >> 8, y1 & 0xFF])
        self.send_cmd(0x2C) # Memory Write (准备开始写像素数据)

    def display(self, image):
        """
        核心函数：将 PIL 图片显示到屏幕上
        关键点：颜色空间转换 (RGB888 -> RGB565)
        """
        if image.size != (self.width, self.height):
            image = image.resize((self.width, self.height))
        
        # 1. 格式转换
        # 电脑图片通常是 RGB888 (红绿蓝各8位，共24位)
        # 嵌入式屏幕为了省带宽，通常用 RGB565 (红5位，绿6位，蓝5位，共16位)
        image_rgb = image.convert("RGB")
        pixels = np.array(image_rgb, dtype=np.uint16)
        
        # 2. 位运算魔法 (Bitwise Magic)
        # R >> 3: 扔掉低3位，保留高5位
        # G >> 2: 扔掉低2位，保留高6位
        # B >> 3: 扔掉低3位，保留高5位
        # << 11/5: 左移，把它们挪到正确的位置拼起来
        r = (pixels[:, :, 0] >> 3) << 11
        g = (pixels[:, :, 1] >> 2) << 5
        b = (pixels[:, :, 2] >> 3)
        rgb565 = r | g | b # 按位或，拼接成最终的 16位 整数
        
        # 3. 大小端转换 (Endianness)
        # SPI 发送是按字节发的，需要把 16位 拆成两个 8位
        high_byte = (rgb565 >> 8).astype(np.uint8)
        low_byte = (rgb565 & 0xFF).astype(np.uint8)
        
        # 4. 展平成一维数组
        data = np.dstack((high_byte, low_byte)).flatten().tolist()
        
        # 5. 发送数据
        self.set_window(0, 0, self.width - 1, self.height - 1)
        
        # 分块发送 (Chunking) 以避免缓冲区溢出 (SPI Buffer Overflow)
        chunk_size = 4096
        GPIO.output(self.dc_pin, GPIO.HIGH)
        for i in range(0, len(data), chunk_size):
            self.spi.writebytes(data[i:i+chunk_size])

    def clear(self, color=(0,0,0)):
        img = Image.new("RGB", (self.width, self.height), color)
        self.display(img)

    def set_backlight(self, val):
        """控制背光: True=亮, False=灭"""
        GPIO.output(self.blk_pin, GPIO.HIGH if val else GPIO.LOW)

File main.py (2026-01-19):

import os
# 在导入任何其他库之前设置环境变量，屏蔽底层驱动的刷屏日志
os.environ["LIBCAMERA_LOG_LEVELS"] = "ERROR" # 屏蔽 libcamera 的 INFO
os.environ["OPENCV_LOG_LEVEL"] = "ERROR"     # 屏蔽 OpenCV 的 WARN

import time
import serial   # 串口通信库 (用于指纹模块)
import sqlite3  # SQLite 数据库库
import datetime # 时间日期库
import threading # 多线程库 (让程序能"分心"做两件事)
import queue    # 线程安全的队列 (用于线程间传话)
import adafruit_fingerprint # 指纹模块驱动
import lgpio    # 树莓派 GPIO 库 (Pi 5 专用)
import warnings # 屏蔽过时警告
from hardware.servo_control import ServoController

# 屏蔽无关紧要的第三方库警告
warnings.filterwarnings("ignore", category=UserWarning, module="face_recognition_models")
warnings.filterwarnings("ignore", message="pkg_resources is deprecated")

from PIL import Image, ImageDraw, ImageFont # 图像处理库
from hardware.st7789_driver import ST7789_Driver
from hardware.face_system import FaceRecognizer
import hardware.enrollment as enrollment

# --- 全局配置 (Constants) ---
SERIAL_PORT = "/dev/ttyAMA0" # 树莓派5 的 UART0 接口
BAUD_RATE = 57600            # 通信波特率 (必须与指纹模块一致)
UNLOCK_TIME = 2.5            # 舵机开锁保持时间 (秒)
DATABASE_NAME = "capsule_dispenser.db"
SCREEN_TIMEOUT = 30          # 屏幕自动休眠倒计时
MAX_SESSION_TIME = 300       # 最大活跃时间 (5分钟)
WAKE_BUTTON_PIN = 26         # 唤醒按钮连接的 GPIO 引脚

# --- 全局变量 (Global Variables) ---
disp = None
font_large = None
font_small = None
servos = {}
h_gpio = None   
face_queue = queue.Queue()      
face_running_event = threading.Event() 

# 核心硬件对象 (全局化以便录入模块调用)
face_rec = None
finger = None
uart = None # Make uart global so we can close it
finger_lock = threading.Lock() # Thread lock for serial port access

def init_display_system():
    global disp, font_large, font_small
    try:
        disp = ST7789_Driver()
        try:
            font_large = ImageFont.truetype("/usr/share/fonts/truetype/dejavu/DejaVuSans-Bold.ttf", 32)
            font_small = ImageFont.truetype("/usr/share/fonts/truetype/dejavu/DejaVuSans.ttf", 22)
        except:
            font_large = ImageFont.load_default()
            font_small = ImageFont.load_default()
        print("屏幕对象初始化完成 / Écran initialisé")
    except Exception as e:
        print(f"屏幕初始化失败 / Erreur init écran: {e}")

def update_screen(status_type, message, bg_color=(0, 0, 0), progress=None, countdown=None):
    if disp is None: return
    disp.set_backlight(True)
    image = Image.new("RGB", (disp.width, disp.height), bg_color)
    draw = ImageDraw.Draw(image)
    draw.rectangle((5, 5, disp.width-5, disp.height-5), outline="WHITE", width=2)
    draw.text((10, 30), status_type, font=font_large, fill="WHITE")
    
    y_pos = 80
    line_height = 30
    for raw_line in message.split('\n'):
        while len(raw_line) > 18:
            sub_line = raw_line[:18]
            draw.text((10, y_pos), sub_line, font=font_small, fill="WHITE")
            y_pos += line_height
            raw_line = raw_line[18:]
        if raw_line:
            draw.text((10, y_pos), raw_line, font=font_small, fill="WHITE")
            y_pos += line_height
    
    if progress is not None:
        bar_x, bar_y, bar_w, bar_h = 20, 180, 200, 10
        draw.rectangle((bar_x, bar_y, bar_x + bar_w, bar_y + bar_h), outline="WHITE", width=1)
        fill_w = int(bar_w * progress)
        if fill_w > 0:
            draw.rectangle((bar_x + 1, bar_y + 1, bar_x + fill_w, bar_y + bar_h - 1), fill="WHITE")

    current_time = datetime.datetime.now().strftime("%H:%M:%S")
    draw.text((60, 205), current_time, font=font_small, fill="YELLOW")

    if countdown is not None:
        color = "RED" if countdown < 10 else "GREEN"
        draw.text((180, 205), f"{int(countdown)}s", font=font_small, fill=color)

    disp.display(image)

def log_access(user_id, event_type, status, message=""):
    try:
        conn = sqlite3.connect(DATABASE_NAME)
        cursor = conn.cursor()
        timestamp = datetime.datetime.now().strftime("%Y-%m-%d %H:%M:%S")
        cursor.execute("INSERT INTO Access_Logs (user_id, timestamp, event_type, status, detail_message) VALUES (?, ?, ?, ?, ?)", 
                       (user_id, timestamp, event_type, status, message))
        conn.commit()
        conn.close()
    except Exception as e:
        print(f"日志记录失败 / Erreur Log: {e}")

def get_user_info(user_id):
    if user_id == 0: return ("Mobile App", 1, None)
    try:
        conn = sqlite3.connect(DATABASE_NAME)
        cursor = conn.cursor()
        cursor.execute("SELECT name, auth_level, assigned_channel FROM Users WHERE user_id = ?", (user_id,))
        result = cursor.fetchone()
        conn.close()
        return result if result else ("Unknown", 0, None)
    except Exception:
        return ("Unknown", 0, None)
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

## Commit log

2025-12-08 feat: Upgrade to 4x SG90 servos with Pi 5 hardware PWM support
2025-12-08 Update: Optimized UI font size (32px/22px) and finalized 4-servo software PWM config
2025-12-17 refactor: move servo test code to servo_control.py and update docs
2025-12-17 feat: create integrated hardware_test.py and refactor servo_control
2025-12-17 fix: hardware_test fingerprint attr error and screen clear
    [hardware_test.py]
2025-12-17 fix: Robustify fingerprint device address printing in hardware_test.py
    [hardware_test.py]
2025-12-17 feat: implement soft start for servos to reduce power spikes
2025-12-17 fix: increase servo move duration to 2.0s to fix screen dimming
    [servo_control.py]
2025-12-17 revert: servo smooth move due to ineffectiveness and new issues
    [servo_control.py]
2025-12-29 feat: enhance fingerprint auth and user enrollment with multi-language support
    - Update to be fully bilingual (Chinese/French), removing English and adding emojis.
    - Insert Raspberry Pi 5 GPIO pinout diagram into .
    - Refactor to support and .
    - Rewrite for interactive user management, including listing users and assigning channels.
    - Update to enforce role-based access control (Admin/User) and channel-specific servo unlocking.
2025-12-29 fix: correct indentation in fingerprint_enroll.py
    [fingerprint_enroll.py]
2025-12-29 refactor: strict role separation - admins no longer have physical channels, fix indentation
    [main_demo.py]
2025-12-29 feat: add real-time clock and fix update logic in main_demo.py
    [main_demo.py]
2025-12-29 fix: clock update precision and backlight off on exit
    [main_demo.py]
2025-12-29 fix: restore on-screen unlock countdown
    [main_demo.py]
2025-12-29 docs: update face_recognition install steps & fix camera init on Pi 5
    [face_enroll.py]
2025-12-29 feat: add camera support (Pi 5) and docs
2025-12-29 fix: update face enroll pipeline and docs for Pi 5
    [face_enroll.py]
2025-12-29 debug: add camera diagnostic script
2025-12-29 fix: implement multi-strategy camera initialization for better Pi 5 compatibility
    [face_enroll.py]
2025-12-29 fix: relax face recognition tolerance to 0.6 and add debug logs
    [face_system.py]
2025-12-29 fix: exhaustive V4L2 device search and debug image capture
    [face_system.py]
2025-12-29 fix: adjust face matching threshold to 0.72 for better UX
    [face_system.py]
2025-12-29 refactor: reorganize project structure (move drivers to hardware/, tools to tools/)
2025-12-29 fix: use absolute paths for database connection in tool scripts
    [face_enroll.py, fingerprint_enroll.py, setup_database.py]
2025-12-29 ui: move progress bar and clock down to avoid text overlap
    [main.py]
2025-12-29 fix: remove image downscaling to improve face detection rate
    [face_system.py]
2025-12-29 fix: implement aggressive CLAHE enhancement and debug snapshot
    [face_system.py]
2025-12-29 fix: cleanup debug image logic, keep CLAHE
    [face_system.py]
2025-12-30 fix: run systemd service as current user to access pip libs
2025-12-30 docs: update wiring, readme, and add sleep/wake button logic
2025-12-30 refactor: migrate button input from RPi.GPIO to lgpio for stability
    [main.py]
2025-12-30 fix: restore dynamic clock update in active mode
    [main.py]
2025-12-30 feat: add session timeout, button extend, and countdown UI
2025-12-30 refactor: implement multi-threading for linear UI updates
2025-12-30 fix: remove duplicate code block at end of file
    [main.py]
2025-12-30 feat: implement interrupt-based button handling to fix button responsiveness
    [main.py]
2025-12-30 docs: update project status with latest button interrupt fix
2025-12-30 fix: use hybrid button check (interrupt + polling) for reliability
    [main.py]
2025-12-30 refactor: revert to polling-based button handling for simplicity
    [main.py]
2025-12-31 Refactor: Align servo channel mapping with WIRING_GUIDE (1-5)
2025-12-31 Refactor: Remove default channel in ServoController to ensure explicit config
2025-12-31 Fix: Correct indentation and add warning message in ServoController
    [servo_control.py]
2026-01-01 Refactor: Cleanup camera init and correct learning progress status
    [face_system.py]
2026-01-17 docs: add LaTeX presentation slides and update project status feat(camera): fix 90-degree rotation issue and optimize recognition threshold refactor: remove MQTT from roadmap, focus on REST API
    [face_enroll.py, face_system.py]
2026-01-17 fix(hardware): correct camera rotation to CCW and relax face threshold to 0.68 fix(wiring): update servo 2-5 pin assignments in code and docs
    [face_enroll.py, face_system.py, servo_control.py]
2026-01-17 style(face): clarify log terminology from 'Distance' to 'Feature Diff' to prevent physical distance ambiguity
    [face_system.py]
2026-01-17 fix(main): resolve NameError by ensuring update_screen function is defined before usage
    [main.py]
2026-01-17 fix(main): correct indentation error in sleep timeout logic
    [main.py]
2026-01-17 feat(enroll): integrate wireless face/fingerprint enrollment via app commands
2026-01-17 docs(api): align specs with simplified auth flow (create-as-bind) and update reference
2026-01-17 fix(main): resolve syntax error in display functions docs: update diapo and add Chinese logic guide refactor(api): finalize user management and token-based auth
    [main.py, setup_database.py]
2026-01-17 fix(main): cleanup main loop logic and fix IndentationError
    [main.py]
2026-01-17 revert(ux): remove QR code display feature to simplify hardware logic
    [main.py]
2026-01-17 style(main): finalize main loop logic and fix micro-indentation issues
    [main.py]
2026-01-17 refactor(main): remove button session extension feature to simplify interaction logic
2026-01-18 fix(android): simplify IP input and fix login/bind flow
    - Default IP set to 192.168.4.1 (stripped protocol/port for cleaner UI).
    - Auto-normalize IP input: users only need to type the IP address.
    - Forced UI transition to Dashboard after successful binding.
    - Ensured 'Create User' card is visible during the bind step.
2026-01-18 fix(hardware): add 30s timeout to fingerprint enrollment to prevent system freeze
    [enrollment.py]
2026-01-18 feat(android): finalize stable v1.1 UI and logic
    - Applied vivid color palette with dark grey text for better aesthetics.
    - Optimized channel selection buttons (size, spacing, animations).
    - Removed redundant admin user creation and dangerous demo mode.
    - Improved dashboard greeting and enrollment status feedback.
    - Fixed NullPointerException in initViews.
2026-01-18 feat: implement finger selection dialog during enrollment
    - Android: Added Material selection dialog for finger type.
    - API: Updated /enroll_finger to accept finger_label.
    - Hardware: Sync finger label to the Pi screen during enrollment.
2026-01-18 revert: remove finger selection feature to restore system stability
    [enrollment.py, main.py]
2026-01-18 feat(android): final V1.1 UX refinements
    - One-click Wi-Fi connection logic (Android 9/10+ support).
    - Added 'Retour' button to registration screen.
    - Auto-hide keyboard on action button clicks.
    - Cleaned up terminology (Removed 'API' references).
    - Documentation updated to reflect latest release status.
2026-01-18 feat(hardware): add fingerprint sensor watchdog and update docs
2026-01-18 fix(main): correct indentation error in fingerprint initialization
    [main.py]
2026-01-18 fix(main): safely release lgpio and resources on exit to prevent crashes
    [main.py]
2026-01-18 style(android): update delete buttons to soft red (#E57373) for better UX
2026-01-18 release: DistCapsule V1.1 Production
    - Finalized 20-min LaTeX presentation (UTF-8, fixed compilation).
    - Android App: Applied 'Vivid Palette' UI and hardened security.
    - Hardware: Implemented UART Watchdog for sensor resilience.
    - Code: Cleaned up duplicate resources and legacy strings.
    - Docs: Synchronized README and status reports.
2026-01-19 Disable fingerprint watchdog - feature does not fix hardware failures
    [main.py]
2026-01-19 perf(hardware): reduce servo unlock time to 2.5s and update wiring diagram
2026-01-19 fix(main): resolve float type error in unlock countdown loop caused by UNLOCK_TIME change
    [main.py]
2026-01-21 Update les images de slides
2026-01-26 docs: sync architecture docs & cleanup tools; feat: strict face threshold 0.35
    [Base_Distributeur.scad, Base_Distributeur_Bottom.scad, Base_Distributeur_Combined.scad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]
2026-01-27 Add drawer patch and assembly SCAD
    [Drawer_patch.scad, Drawer_with_patch.scad]
